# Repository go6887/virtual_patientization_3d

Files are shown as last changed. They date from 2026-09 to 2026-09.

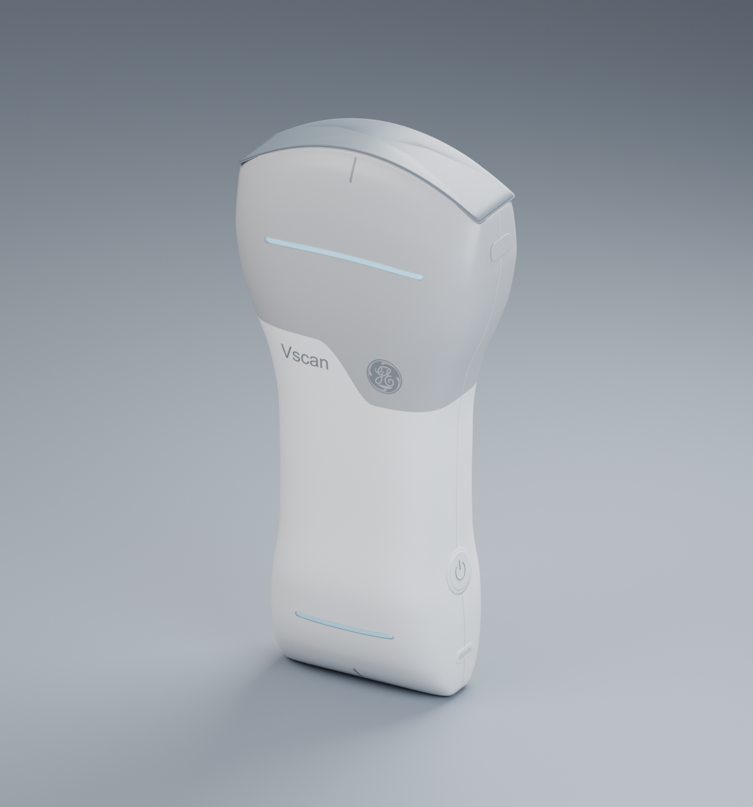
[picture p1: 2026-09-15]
assets/Vscan_Air_CL/Vscan_Air_CL_preview.png

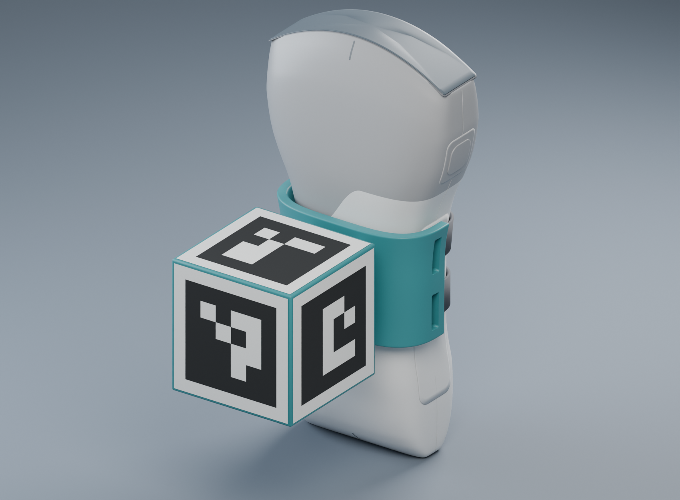
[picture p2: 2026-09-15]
assets/Vscan_marker_attachment/attachment_on_probe.png

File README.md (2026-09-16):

# Vscan Air CL — Webカメラ追跡 / Rerun

プローブに装着した5面のArUcoマーカをWebカメラで検出し、プローブとアタッチメントのOBJをRerun上で動かします。カメラを固定したときの、カメラに対する位置・姿勢を表示します。

`assets/Vscan_marker_attachment/marker_geometry_42mm.json` の **DICT_4X4_50 / ID 0〜4 / 黒枠32 mm / 台42 mm** を使用します。資料のDesktopパスではなく、リポジトリ内のassetsを読み込みます。

## まずデモを動かす

Python 3.14と[uv](https://docs.astral.sh/uv/)を使用します。リポジトリのルートで実行してください。

```bash
uv sync
uv run probe-tracker demo
```

Rerunが開き、左にプローブ・アタッチメント・マーカの3D表示、右に検出画像、下に状態と再投影誤差を表示します。デモは10秒間です。カメラは使わず、移動するマーカ画像を生成して**実際のArUco検出・姿勢推定に通します**。録画のタイムラインを動かして再生できます。

```bash
# デモを記録し、あとから開く
uv run probe-tracker demo --no-viewer --save output/demo.rrd --no-realtime
uv run rerun output/demo.rrd
```

## 腎臓にビームを当てる

`--kidney` を付けると、右腎モデルを小さな立方体（ボクセル）で表示し、プローブの動きに合わせて走査断面との交差を判定します。通常起動では「腎臓の位置・大きさ」操作パネルも開きます。

```bash
# カメラなしで、現在の交差・履歴・非交差を確認
uv run probe-tracker demo --kidney

# 時間制限なしで、操作パネルから移動・拡大縮小を試す
uv run probe-tracker demo --kidney --max-frames 0

# 実物のプローブで操作（プレビュー画面のRキーで履歴を消去）
uv run probe-tracker track --camera 0 --kidney --preview

# 腎臓と走査断面の状態も録画し、あとから再生
uv run probe-tracker demo --kidney --no-viewer --save output/kidney_demo.rrd --no-realtime
uv run rerun output/kidney_demo.rrd
```

- **緑**は現在交差している立方体、**黄**は過去に交差した立方体です。現在の交差を優先して緑で表示します。
- 未走査の外形は、はっきりしたオレンジ色の枠線で表示します。内部まで判定し、立方体間の描画上の隙間は判定に影響しません。
- 状態欄に交差の有無・個数と、累積着色数・割合を表示します。割合の分母は腎臓全体のボクセル数で、現在の交差も履歴に含まれます。
- プレビュー画面を選択して **R** を押すと、現在の交差を残して累積履歴を消去します。次の有効フレームから履歴を再蓄積します。履歴は実行ごとに初期化されます。
- **LOST** の間はプローブ・走査断面・緑の現在色を消し、判定不可（`UNAVAILABLE`）と表示します。固定した腎臓と黄色の履歴は保持し、再検出すると判定を再開します。

操作パネルでは次の操作ができます。画像処理中も操作を受け付け、連続クリックの移動量を合計した最新位置・大きさを次の描画に反映します。

- **位置**：X・Y・Zの数値を入力して適用するか、各軸の＋／−ボタンで移動します。移動量は1・5・10・25 mmから選べます。
- **大きさ**：スライダー、数値入力、＋／−ボタンで**10〜500％**に変更します。100％が元の実寸で、腎臓中心を保って全方向を同じ倍率で拡大・縮小します。
- **初期配置へ戻す**：起動時の位置と倍率に戻します。着色履歴は保持します。
- **履歴を消去**：現在の交差を残して黄色の履歴を消します。
- **終了**：終了ボタンまたは操作パネルを閉じることで追跡を終了します。Ctrl+CやプレビューのQ/Escでも終了できます。

移動や拡大・縮小は表示と交差判定の両方に反映され、LOST中でも配置を変更できます。履歴は腎臓の各ボクセルに付いて動きます。拡縮時はボクセルの一辺も同じ倍率で変わり、ボクセルの個数は変わりません。位置・倍率の変更も録画され、`.rrd`のタイムラインを戻すと当時の配置で表示されます。

操作していない間、腎臓は**カメラ座標に固定**されます。カメラを固定したままプローブを動かしてください。起動時に次のオプションを指定できます。

| オプション | 初期値 | 意味 |
|---|---|---|
| `--kidney-position-mm X Y Z` | `0 -180 400` | 腎臓の境界ボックス中心。カメラ基準でX右・Y下・Z前方、単位mm |
| `--kidney-rotation-deg RX RY RZ` | `0 0 0` | 腎臓中心まわりの回転。固定軸X→Y→Zの順、単位度 |
| `--kidney-scale` | `1` | 腎臓の初期倍率（0.1〜5）。例：`1.5`で150％ |
| `--no-kidney-controls` | 未指定 | 操作パネルを開かずに実行 |
| `--voxel-mm` | `3` | 立方体の一辺（1〜10 mm） |
| `--beam-depth-cm` | `15` | レンズ曲面からの走査深さ（0より大きく24 cm以下） |
| `--beam-angle-deg` | `60` | 走査断面の表示角（0より大きく60度以下） |

```bash
uv run probe-tracker track --kidney --preview \
  --kidney-position-mm 0 -180 400 --kidney-rotation-deg 0 0 30 \
  --beam-depth-cm 15 --beam-angle-deg 60 --voxel-mm 3
```

初期配置は既存の10秒デモで交差と非交差を確認できる位置です。実物では取り付け方向や作業範囲に合わせて位置・角度を指定します。プローブ表示と判定には同じ平滑化済み姿勢を使います。

`--no-viewer`で録画する場合は操作パネルも開きません。明示的に`--kidney-controls`を付ければパネルだけ開けます。パネルはPythonのTkinterを使います。Tkinterが使えない環境では`--no-kidney-controls`を指定し、起動オプションで配置を設定してください。既に保存した録画の再生画面からは操作できないため、配置を変更するときは`track`または`demo`を起動します。

走査断面はプローブOBJのコンベックス側レンズに合わせた、厚みゼロの有限な扇形です。各立方体と面積を持って交差すると着色し、点・辺だけの接触は除外します。実際のビームの厚みや音響強度を再現するものではありません。右腎STLは `assets/kidney/` に同梱し、外部のDesktopフォルダには依存しません。`--kidney` を省略すると従来の追跡表示になります。

## Webカメラで追跡する

```bash
uv run probe-tracker track --camera 0
```

少なくとも1面のマーカ全体をカメラに見せます。複数面が見えると安定しやすくなります。Rerun画面を閉じても取得プロセスは継続するので、終了は実行元で **Ctrl+C**。`--preview` を付けるとOpenCVの小窓でも確認でき、そこで **Q / Esc** で終了できます。

- macOSでカメラを開けない場合は、システム設定 → プライバシーとセキュリティ → カメラで、実行元のターミナルまたはCodexのアクセスを確認します。外付けカメラは `--camera 1` などを試します。
- 初回は水平画角60°を仮定します。概略の動作確認用で、位置・距離の正確さは保証しません。`--fov 70` のように変更できます。
- 校正ファイル `config/camera.json` がある場合は自動で使用します。
- マーカを見失ったとき、または整合する姿勢が得られないときは **LOST** と表示し、現在の3Dプローブを非表示にします。再検出すると復帰します。
- `--smooth 0.35` が標準の平滑化係数です。`--smooth 1` で平滑化を無効にできます。画像上の軸と誤差は平滑化前、3Dモデルと位置表示は平滑化後です。

```bash
# 表示しながら録画
uv run probe-tracker track --camera 0 --save output/session.rrd

# 別の校正ファイル・取得解像度を指定
uv run probe-tracker track --camera 1 --width 1280 --height 720 --calibration config/external_camera.json

# カメラの録画ファイルや静止画を処理
uv run probe-tracker track --video path/to/video.mp4 --calibration config/camera.json
uv run probe-tracker track --image assets/Vscan_marker_attachment/attachment_on_probe.png
```

静止画の組立レンダーは検出確認用です。そのレンダーのカメラ内部パラメータは付属しないため、姿勢・距離の正解値比較には使えません。未校正設定ではIDを検出できても姿勢の品質チェックでLOSTになります。姿勢までの動作確認には `demo` を使用してください。

### LOSTが多い場合の診断

映像上部とRerunの状態欄に、直近60フレームの結果を表示します。ターミナルには2秒ごとの累計と終了時の集計も表示します。LOSTの瞬間を目で追う必要はありません。

```bash
uv run probe-tracker track --camera 0 --width 1280 --height 720 --preview --diagnostics output/tracking_diagnostics.jsonl
```

普段の動かし方で20〜30秒試し、Qで終了します。診断ファイルには各フレームの判定理由、ID、マーカの画素寸法、歪み補正後の四隅、再投影誤差を保存します。再実行時はセッションを追記します。

| 表示・ログの理由 | 意味・切り分け |
|---|---|
| NO ID / `no_markers` | 使用可能なIDがない。距離・ぼけ・反射・遮蔽などを確認。生のIDも記録するので未知ID・重複IDの除外と区別できる |
| POSE / `pose_rejected` | IDは得られたが、再投影誤差・奥行き・面の向きのいずれかが条件を満たさない。これだけで原因を校正誤差に断定はできない |
| CONFLICT / `inconsistent_faces` | 複数面が検出されたが、整合する姿勢に2面以上が同意せず、過去の姿勢でも選べない。貼付位置・IDの面配置・紙の上方向・校正値を確認 |
| CORNERS / `invalid_corners` | 使用可能な四隅になっていない（退化した形、極小領域など） |

現在の実装は1フレームの不採用でLOSTにし、履歴をリセットします。複数面の不整合が続くと、そのままでは復帰しにくい場合があります。一度1面だけを正面寄りに見せて復帰するかが切り分けになります。診断追加によって採用条件や4 pxの閾値は変えていません。

## カメラを校正する

1. チェスボードを生成し、拡大縮小なしの **100%** で印刷します。マーカラベルのPDFとは別の用紙です。

   ```bash
   uv run probe-tracker board --output output/chessboard.svg
   ```

   標準は内側の交点9×6、1マス20 mm、余白込み240×180 mmです。A4横向きで印刷でき、白黒の境界間が20 mmであることを実測します。平らで硬い板に固定してください。

2. 追跡と同じカメラ・解像度で校正を起動します。

   ```bash
   uv run probe-tracker calibrate --camera 0 --width 1280 --height 720
   ```

3. ボード全体が検出されたら **Space** で採用。画面の中央・端、距離、傾きを変え、15枚以上集めます。同じ構図の連続採用は抑制されます。
4. **C** で計算し `config/camera.json` に保存します。**Q / Esc** は保存せず終了します。再投影誤差も出力されます。
5. `uv run probe-tracker track --camera 0` で追跡します。

カメラの画角・クロップ・フォーカス設定を変更した場合は再校正してください。同じアスペクト比の単純な画像リサイズには内部パラメータを拡縮しますが、異なるアスペクト比はエラーにします。同じ比率でもクロップが変わるカメラモードには別の校正が必要です。レンズ歪みを補正した映像を検出・Rerun表示の双方に使用します。

## 座標と表示の意味

全体の単位は **mm**。カメラ座標はOpenCVの **X右・Y下・Z前方** です。推定するのはマーカキューブ中心の `camera_from_cube` です。

資料の組立変換は `probe_from_cube` なので、OBJを表示するときは逆行列を合成します。

```text
camera_from_probe = camera_from_cube @ inverse(probe_from_cube)
```

プローブOBJを原点中心に移動し直したり、メートルとして読んだりしません。プリント用アタッチメントOBJは別の造形座標なので、組立データと照合した変換を適用します。詳細は [assetsの検証記録](docs/asset_validation.md) を参照してください。

1面のときは平面PnPの候補解、複数面のときは各面の候補と非平面の組合せを評価します。再投影誤差、カメラ前方、面の向き、面同士の整合性を確認してから採用します。重複IDや未知のIDは使用しません。単面の正面付近には姿勢の曖昧さが残り、手・反射・ブレで黒枠が欠けると追跡できません。

**カメラ校正とプローブの取り付け校正は別です。** 付属JSONのプローブ位置はCAD上の推定値です。紙・接着層の厚さ、固定位置、再装着のずれは含まれません。表示位置はプローブモデルの原点であり、超音波画像面やレンズの接触点の校正値ではありません。今回の実装は追跡・表示の試作です。

## 構成と検証

```text
src/probe_tracking/
  geometry.py     添付JSONと座標変換
  tracking.py     ArUco検出・姿勢推定・平滑化
  camera.py       内部パラメータの読込と解像度整合
  calibration.py  チェスボードとカメラ校正
  synthetic.py    合成マーカ画像の生成
  viewer.py       Rerunへの形状・姿勢・映像・状態の出力
  kidney_scan.py  固定した腎臓の配置・現在の交差・累積履歴
  kidney_view.py  腎臓ボクセルと走査断面の時系列表示
  kidney_controls.py  腎臓の移動・拡大縮小・履歴消去の操作パネル
  kidney_voxels.py / ultrasound_geometry.py / probe_scan_profile.py
                  腎臓のボクセル化・有限断面との交差・レンズ形状
  cli.py          実機・動画・デモの起動
```

```bash
uv run pytest
uv run ruff check src test
```

テストは5面の姿勢復元、複数面の外れ値、重複・未知ID、検出ロスト、座標変換、校正値の復元を含みます。合成デモとRerun記録を確認しています。実物を用いた追跡精度・カメラ校正の検証は別途必要です。

各オプションは `uv run probe-tracker --help`、`uv run probe-tracker track --help` で確認できます。`uv run python src/main.py demo` も使用できます。

実装時の参照: [OpenCVのPnP](https://docs.opencv.org/4.x/d5/d1f/calib3d_solvePnP.html)、[カメラ校正](https://docs.opencv.org/4.13.0/dc/dbb/tutorial_py_calibration.html)、[Rerun Transform3D](https://rerun.io/docs/reference/types/archetypes/transform3d)、[Pinhole](https://rerun.io/docs/reference/types/archetypes/pinhole)。

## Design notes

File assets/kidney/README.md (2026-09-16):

# Right kidney model

`kidney_right.stl` is copied without modification from the reference application
`/Users/goudamasaki/Desktop/test/kidney_right.stl` supplied for this project.
Its original coordinates and millimetre units are preserved. Runtime code loads
this repository copy and has no dependency on the reference application's path.

The scan places the source mesh's bounding-box centre at the configured camera
position, then applies rotations about that centre. The closed surface is filled
with source-aligned cubes at the requested resolution before applying this pose.

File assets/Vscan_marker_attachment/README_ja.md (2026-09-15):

# Vscan Air CL用・位置追跡マーカーアタッチメント

大きい曲面のプローブ側を使う前提で、背面のくびれに取り付ける試作品です。
曲面に沿うサドル、短い補強支柱、5面マーカー台を一体化しています。
前回作成した写真由来の外観モデルに合わせた設計で、実機への装着は未確認です。

## 最初に使うファイル

| ファイル | 用途 |
|---|---|
| `Vscan_saddle_fit_test.obj` / `.stl` | 先に印刷する、装着確認用のサドルだけの試験片 |
| `Vscan_marker_attachment.obj` / `.stl` | マーカー台を含む一体型の本体 |
| `Vscan_marker_attachment_assembly.blend` | プローブ・ベルト・パッド・貼付位置を確認する組立モデル |
| `marker_labels_32mm.pdf` | この台に合うマーカー貼付紙。A4・100%で印刷 |
| `marker_geometry_42mm.json` | マーカーの寸法、面、向き、四隅の3D座標 |

OBJ/STLは1単位=1 mm。印刷部品だけの、閉じた単一メッシュです。MTLは不要です。
Blenderの組立モデルには印刷しない参考プローブ、ベルト、パッド、紙も含みます。

## 準備するもの

- 3Dプリントした本体1個。まずサドル試験片で装着確認。
- 幅10 mm、長さ約200 mmの、伸びにくい面ファスナーバンド2本。
  両端を穴で折り返して固定できる薄いタイプを使用します。必要な長さは実物で調整。
- 10 × 12 mm、厚さ1 mmのシリコンパッド4枚と薄い接着層。
  緩い箇所には0.5 mm刻みで薄いシムを追加します。
- マーカーを貼るための薄い接着材。紙を平らに保ちます。

## 取り付け

1. 大きい曲面レンズを上に、Vscanの文字がある面を正面にして、組立画像と同じ向きに置きます。
2. サドルの内側にパッドを4枚貼ります。左右2か所×上下2か所で、帯を通す穴から離します。
   初期厚さは1 mm。厚いスポンジではなく薄いパッドで隙間を調整します。
3. プローブの背面側にサドルを当てます。上縁は中央の白いくびれ、下縁は電源ボタンより上です。
   内面は参考モデルより約1.6 mm離してあります。実物の形に合わせ、パッドを局所的に調整します。
4. 上下それぞれのバンドを、左右の穴を端部アンカーとしてプローブ前面側に回します。
   バンド両端を各穴に1枚の厚みで通し、サドル前縁の肉部分に回して、前面側のバンド自身へ折り返して留めます。
   折り返した二重部分は穴の外に置きます。穴は約11.4 × 3.2 mmです。
   支柱のあるサドル背面を横切る戻り経路は使いません。
5. レンズ、電源ボタン、表示ランプを避けたまま固定します。
   キューブを軽く押し、プローブとの相対的なずれや揺れを確認します。実機の握り方も確認してください。
6. サドル試験片の装着が良ければ、本体を印刷して同じパッド構成・位置で取り付けます。

パッドや締め付けでは収まらない形状差がある場合は、実測して内面を修正してください。
力ではめ込むスナップ式にはしていません。充電・清掃時には外せる構成です。

## 印刷の開始条件

機種・材料に合わせて調整するための初期案です。

- 材料：PETGを想定。試験片はPLAでも形状確認が可能。
- ノズル0.4 mm、積層0.2 mm、外周4本、上下6層、インフィル15〜20%を目安に設定。
- サポートを有効にします。サドル下面には造形物上から始まるサポートも必要です。
- OBJ/STLは、キューブのID0面をベッド側に向けてあります。本体外寸は約54.3 × 42 × 70 mm。
- 角やベルト穴、パッドが当たる面のサポート痕を仕上げます。マーカーを貼る平面を曲げないでください。

キューブは外形を閉じたCAD形状です。スライサーのインフィル設定で内部を軽くします。
100%充填を前提とした設計ではありません。実際の重量・造形時間はスライサーで確認してください。

## マーカーの貼り方と追跡設定

台の外寸は42 mm角、黒枠は32 mm角、貼付紙は40 mm角です。
同梱PDFをA4・100%で印刷し、100 mm確認スケールと黒枠32 mmを実測してください。
元の50 mmキューブ／黒枠40 mm用の設定は、そのままでは一致しません。

| ID | 組立時の面 | 紙の上方向 |
|---|---|---|
| 0 | プローブから最も離れた背面側 | 大きい曲面レンズ側 |
| 1 | プローブ正面から見て左側 | プローブから離れる方向 |
| 2 | 大きい曲面レンズ側 | プローブから離れる方向 |
| 3 | プローブ正面から見て右側 | プローブから離れる方向 |
| 4 | 小さい平面レンズ側 | プローブから離れる方向 |

各紙を面の中央、各辺から1 mm内側に貼ります。支柱が付く面には貼りません。
組立モデルの黒白模様は貼付位置を示す参考表示で、印刷用OBJ/STLには入っていません。

`marker_geometry_42mm.json`は説明用の幾何データです。既存の`marker_model.json`と同じ形式とは限りません。
使用する追跡ソフトに、黒枠寸法・各面の位置・向き・角の順序を反映してください。
JSON内のプローブとの位置関係はCAD上の推定値で、実機での校正結果ではありません。
紙・接着層の厚み、実際の固定位置、プローブ基準点や超音波画像面との対応は実機で校正してください。
再装着やパッド構成変更時も、この対応を確認します。

## 今回確認した範囲

- 本体・試験片とも、単一の閉じたメッシュ。OBJ/STLの面・接続・再読み込みを検証済み。
- 参考プローブの全部品との幾何学的な交差なし。
- 5面のマーカー四隅は所定の平面上。PDFのIDは元資料と一致。
- 組立レンダーから、見えているID0・1・2およびID3をOpenCVで検出。

実物のはまり方、保持力、印刷強度、カメラ実写での追跡精度は未検証です。
まず机上で試験片の装着と固定を確認するための初回試作として使用してください。

作成：2026-09-10 / Blender 5.2.1

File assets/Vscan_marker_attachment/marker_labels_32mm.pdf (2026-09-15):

# プローブアタッチメント / マーカー貼付紙

42 mm キューブ用・ArUco DICT_4X4_50・ID 0〜4

このPDFを A4・倍率100%（実際のサイズ）で印刷してください。

「用紙に合わせる」は無効。元PDF用の80%設定は、このPDFには使いません。

黒枠の外寸：32 × 32 mm / 切り取り枠：40 × 40 mm / 白い余白：各4 mm

切る前に、IDと紙の上方向を裏面に記入。42 mmの各平面の中央に貼ります。

ID 0 / +Z 面（天面）

紙の上側を +Y 方向へ

ID 1 / +X 面

紙の上側を +Z 方向へ

ID 2 / +Y 面

紙の上側を +Z 方向へ

ID 3 / -X 面

紙の上側を +Z 方向へ

ID 4 / -Y 面

紙の上側を +Z 方向へ

### 貼り付けの基準

紙の白い枠も残して切る。

台の各辺から1 mm内側に

40 mm角の紙を配置する。

-Z 面は取付部。貼付なし。

原点：キューブ中心。面・ID・紙の向きは添付の座標JSONと一致させてください。

座標JSONは幾何情報の見本です。使用する追跡ソフトの形式に合わせて設定します。

紙・接着層の厚みと取付後の姿勢を反映し、プローブ／超音波画像面との対応を校正。

印刷後に実測：下のスケール100 mm、各マーカー黒枠32 mm、切り取り枠40 mm。

0 | 100 mm

研究・机上試作用 / 実物への装着・追跡精度は未検証 / 1ページ

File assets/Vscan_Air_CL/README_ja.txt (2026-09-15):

GE HealthCare Vscan Air CL — 外観3Dモデル

同梱ファイル
・Vscan_Air_CL.obj：形状データ（部品別メッシュ、UV、法線付き）
・Vscan_Air_CL.mtl：色と材質の定義
・Vscan_Air_CL.blend：編集用のBlender 5.2ファイル
・Vscan_Air_CL_preview.png：モデルのプレビュー

使い方
OBJとMTLを同じフォルダに置いて読み込んでください。
外部テクスチャは使用していません。ロゴと文字もメッシュです。
Blenderで編集する場合は、同梱の.blendを開くと材質・表示設定も引き継げます。

寸法・座標
OBJの1座標単位 = 1 mm。
外形寸法：全長131 mm × 最大幅64 mm × 最大厚み31 mm。
X：幅、Y：厚み、Z：長さ。正面は -Y、コンベックス側は +Z。
原点は全体の外接範囲の中心です。
OBJ自体に単位情報はないため、読み込み先をmmとして扱ってください。
Blenderファイルはメートル法、単位スケール0.001、長さ表示mmに設定しています。

作成内容と精度
製品写真と公表外寸を基に、Blenderで作成した外観の近似モデルです。
本体のくびれ、灰色と白の境界、両端のレンズ、表示ランプ、側面ボタン、
カバー、継ぎ目、方向マーク、Vscan文字とGEロゴを再現しています。
局所の曲率、厚さ、細部の寸法は写真からの推定です。
メーカー公式CAD、内部構造、寸法保証付きの設計データではありません。
各部品が重なる外観用の構成です。単一の造形用ソリッドにはしていません。

主な参照資料
GE HealthCare 日本 製品ページ
https://www.gehealthcare.com/ja-jp/products/ultrasound/vscan-air-cl

GE HealthCare 公式寸法・仕様
https://vscanair-support.gehealthcare.com/support/solutions/articles/47001172608-specifications

GE HealthCare プローブ各部の説明
https://vscanair-support.gehealthcare.com/support/solutions/articles/47001169691-probe-description

GE製ユーザーマニュアル、図3-3（販売店サイトに掲載）
https://apps.soundvet.com/vscan/assets/files/Vscan_2022_user_manual-a0678ce56d8e4ea7b74bcee32e6f62a7.pdf

製品各方向の写真参考
https://quincemedical.com/products/ge-healthcare-vscan-air-portable-ultrasound-systems

GEモノグラムの形状資料
https://upload.wikimedia.org/wikipedia/commons/f/ff/General_Electric_logo.svg

制作：2026-09-06 / Blender 5.2.1

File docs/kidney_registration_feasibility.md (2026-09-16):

# 腎臓セグメンテーションを用いた3Dモデル位置合わせの調査

調査日: 2026-09-16。対象は両リポジトリの現在の作業ツリー。コード・既定checkpointのメタデータ・同梱メッシュ・一次資料を確認した。実機撮像、患者画像や動画の読み込み、セグメンテーション推論、登録精度の実測は行っていない。

提案の「腎臓セグメンテーション→長軸推定→3Dモデルの位置・向き・大きさ合わせ」は、初期配置として有望。推奨する構成は、**良好な長軸断面から仮配置し、追跡済みの複数断面で配置を補正・確定する方法**である。モデルを新規学習する前に、画像とマーカーの空間校正・時刻同期を整える必要がある。現在の情報だけでは、実物の腎臓に対するmm単位の精度や、3 mmボクセルの正確な着色までは保証できない。

現在の実装で確認できた内容は次のとおり。

| 対象 | 確認した事実 | 位置合わせへの意味 |
|---|---|---|
| プローブ追跡 | `camera_from_cube` を推定し、CADの `cube_from_probe` と合成 | 6DoFの位置・姿勢を利用できる。ただしCADと実際の画像面の関係は別途校正が必要 |
| 腎臓配置 | カメラ座標に固定。既定中心は `(0, -180, 400)` mm | 実際の腎位置を観測して置いたものではない |
| 腎臓変換 | 起動時に回転を指定可能。実行中の `set_placement` は位置と等方スケールのみ | 登録結果を反映するには回転も更新できる入口が必要 |
| 走査断面 | プローブOBJ外形のレンズから推定した有限の扇形 | 実際の超音波画素との対応が未校正。表示と登録で同じ校正済み幾何を使う必要がある |
| 交差判定 | 厚みゼロの扇形とボクセルの交差を判定 | 幾何学的な通過履歴。超音波で実際に見えた範囲や画像品質の保証とは区別する |
| 腎臓メッシュ | 右腎の閉じたSTL。現在の被験者・ファントムとの形状一致を示す情報はない | 汎用テンプレートとして使う。等方拡縮で個体形状まで一致するとは限らない |

実装の根拠: [姿勢の合成と交差更新](/Users/goudamasaki/ghq/github.com/go6887/virtual_patientization_3d/src/probe_tracking/cli.py:324)、[腎臓の初期配置](/Users/goudamasaki/ghq/github.com/go6887/virtual_patientization_3d/src/probe_tracking/kidney_scan.py:97)、[実行中の位置・スケール更新](/Users/goudamasaki/ghq/github.com/go6887/virtual_patientization_3d/src/probe_tracking/kidney_scan.py:139)、[外形からの走査面推定](/Users/goudamasaki/ghq/github.com/go6887/virtual_patientization_3d/src/probe_tracking/probe_scan_profile.py:1)、[CADと実機校正の区別](/Users/goudamasaki/ghq/github.com/go6887/virtual_patientization_3d/docs/asset_validation.md:15)。

同梱STLを読み取った結果、座標軸に沿った外接寸法は約52.59 × 53.26 × 98.44 mm、体積は約120.56 cm³。これらはメッシュの測定値であり、実物の腎寸法ではない。現在の配置基準は外接箱中心で、メッシュの体積重心とは約1.81 mm異なる。登録で求めた「中心」が画像重心、体積重心、外接箱中心のどれかを明確にし、変換するときに混同しない。

参考リポジトリの既定モデルは、`models/segmentation/best.pt`。checkpointを安全な重み読み込みで確認したところ、**SegFormer / MiT-B4、512 × 512グレースケール入力、単一フレームの2Dモデル**だった。クラスは背景・`renal_cortex`・`central_echo_complex`。ラッパー名は `Mid25dSegmenter` だが、既定checkpointの `n_frames` は1である。2.5D候補も存在するが、その時間窓は3D位置や断面間隔を復元するものではない。

入力はクロップ済み画像で、推論用にリサイズした後、出力マスクをクロップ後の元解像度へ戻す。そのため、3D変換に使うのは表示用の縮小画像や512²入力上の座標ではなく、クロップ・リサイズを追跡した画像座標である。[モデル設定](/Users/goudamasaki/ghq/github.com/go6887/virtual_patientization/src/configs/constants.py:51)、[checkpointからのモデル構築](/Users/goudamasaki/ghq/github.com/go6887/virtual_patientization/src/segmentation/factory.py:13)、[推論と座標復元](/Users/goudamasaki/ghq/github.com/go6887/virtual_patientization/src/segmentation/mid25d.py:145)。

既存コードは皮質とCECの和集合を結合腎領域として利用し、全画素の重心・共分散からPCA長軸を求めている。この計算を初期配置の参考にできる。ただし、既存関数の出力は病変配置用アンカーであり、3D姿勢推定APIではない。外輪郭を腎全体の輪郭の近似として使えるかは、対象データのアノテーション定義と手動の腎外輪郭で確認する。[PCA実装](/Users/goudamasaki/ghq/github.com/go6887/virtual_patientization/src/lesion/placement.py:242)。

このPCAの符号は画面右下方向にそろえており、解剖学的な上極・下極の判別ではない。また、ほぼ円形のマスクでは画面x/y軸にフォールバックする。3D登録へ移す際は、こうした断面を「長軸の信頼性が低い」と扱う必要がある。長軸の計算は物理スケールを反映した座標で行い、縦横倍率の異なるリサイズ画像から得た角度をそのまま使わない。

既定checkpointに保存されたvalidation Diceは皮質0.79432、CEC0.78542、平均0.78987だった（validation `job10`、epoch21）。今回再評価した値ではなく、腎全体の外輪郭精度・長軸角度・3D位置誤差を表す値でもない。別の2.5D候補の約0.896という値は別モデル・別分割であり、同一元動画の重複などの留保がある。未知の人、装置、ファントムに対する性能は別に評価する必要がある。[2.5D候補の評価条件と限界](/Users/goudamasaki/ghq/github.com/go6887/virtual_patientization/docs/cvat_primary_25d_area_threshold_calibration.md:62)。

単一断面から直接観測できるのは、腎臓全体ではなく「撮影平面と腎臓が交差した断面」である。以下は幾何学的な判断であり、今回の実機実験結果ではない。

| 2Dマスクから得る量 | 初期値への利用 | 確定できないこと |
|---|---|---|
| マスク重心 | 断面の中心を3D位置へ変換 | 腎臓全体の中心が断面外にどれだけ離れているか |
| PCA長軸 | 断面内の主方向を3D方向へ変換 | 本当に3D長軸を含む断面か、長軸回りの回転、上極・下極 |
| 長径 | 良好な中心長軸断面ならスケールの初期値 | 見かけの短さが個体サイズによるのか、切り方によるのか |
| 短径 | 断面内の幅の初期値 | 断面外の厚みと個体固有の形状 |

仮想的な楕円体で考えると、長さ110 mm、奥行50 mmの物体を、中心から奥行方向に15 mmずらした長軸に平行な平面で切ると、断面の長さは88 mmになる。断面の縮小率は `sqrt(1 - (15/25)^2) = 0.8`。これは「物体全体を0.8倍にし、中心を撮影平面まで移したモデル」の中心断面と同じである。したがって完全なセグメンテーションでも、単一断面のサイズと面外位置を区別できない例がある。数値は原理の説明用であり、実腎臓の測定値ではない。

形状が正確に既知で非対称なモデルなら、単一断面の輪郭全体への当てはめで姿勢推定が成立する場合もある。しかし、汎用腎モデル・個体差・見切れのある画像で、一意かつ安定した配置を期待する根拠には乏しい。「細長い断面が得られた」というだけで真の長軸断面を確認したことにはならない。

画像を3Dへ置くために必要な変換は、次のように整理できる。

```text
超音波画素 (u, v)
  → g(u, v): 画像平面内の物理座標 [mm]
  → marker_from_image: 画像平面からプローブマーカーへの校正変換
  → camera_from_marker(t): その画像を撮影した時刻の追跡姿勢
  → カメラ座標中の3D点

p_camera = camera_from_marker(t) @ marker_from_image @ g(u, v)
```

`g` は同次座標として表し、画像形式に応じて定義する。通常の表示済みBモード画像なら画像上の物理スケール・原点・左右反転・クロップを扱う。生のビーム角度/距離データなら対応する扇形変換が必要。扇形に見える表示画像を、その理由だけで再び極座標変換しない。深度、ズーム、クロップ、解像度を変えた場合は、校正との対応を確認する。

**画像面からマーカーへの変換を直接校正すれば、写真由来OBJの音響形状を正しいと仮定する必要はない。** その校正値から3D表示の走査面と着色判定も定義する。腎臓だけを移動して見た目を合わせると、プローブを別方向へ動かした際に画像面の誤差が再び現れる。

空間校正には、既知位置の点・ワイヤーなどを異なるプローブ姿勢から撮像する方法がある。カメラ内部パラメータの校正とも別の工程である。現状は内部校正JSONが指定されなければ仮の画角から内部パラメータを作るため、実物への登録では校正済みカメラと実寸のマーカーを使う。[カメラ設定](/Users/goudamasaki/ghq/github.com/go6887/virtual_patientization_3d/src/probe_tracking/cli.py:254)。画像面と追跡センサーの相対姿勢を求める必要性は、[Pragerらのfreehand US校正論文](https://pubmed.ncbi.nlm.nih.gov/9740387/)でも扱われている。

時刻は「推論が終わった時刻」ではなく「画像内容が取得された時刻」に対応させる。参考リポジトリには受信時刻から映像遅延を引く設計があるが、現在の `CAPTURE_LATENCY_S=0.180` を別構成へそのまま移せない。コメントに残る測定条件と数値にも留保があり、超音波装置内・キャプチャ経路・Webカメラ経路を含む相対遅延を再測定する。[遅延設定](/Users/goudamasaki/ghq/github.com/go6887/virtual_patientization/src/configs/constants.py:39)、[内容時刻への補正](/Users/goudamasaki/ghq/github.com/go6887/virtual_patientization/src/processing/pipeline.py:109)。時刻オフセットを測る公式実装例は [PLUS Toolkit](https://github.com/PlusToolkit/PlusLib/blob/master/docs/algorithms/AlgorithmTemporalCalibration.md) にある。固定オフセットの補正だけでは可変の遅延は消えない。

現在の3d側はWebカメラ取得前の経過時間を記録しており、超音波映像と共通の内容時刻で結ばれてはいない。また、登録に使う姿勢をそのまま表示用の平滑化姿勢にすると移動中の遅れを含む。最初は静止姿勢で撮影し、続いて内容時刻に合わせた姿勢補間を評価する。[時刻と平滑化](/Users/goudamasaki/ghq/github.com/go6887/virtual_patientization_3d/src/probe_tracking/cli.py:374)。

参考リポジトリのマスク後処理にも注意が必要。既定ではEMAを使用し、品質不良時は直前マスクを最大2フレーム保持する。3D点群を作るときに古いマスクを新しいプローブ姿勢で変換すると、架空の輪郭が生じる。初期検証では現在フレームのマスクと連結成分処理を使い、EMA保持を外す方法が分かりやすい。現在のAPIはマスクと処理時間のみで、確率や保持中フラグは返さないため、品質情報が必要なら拡張する。[後処理設定](/Users/goudamasaki/ghq/github.com/go6887/virtual_patientization/src/configs/constants.py:54)、[結果型](/Users/goudamasaki/ghq/github.com/go6887/virtual_patientization/src/segmentation/base.py:23)。

具体的な初期検証は、以下の順番を推奨する。いずれもこれから実施する設計案である。

1. **固定ファントムで画像面校正を検証する。** カメラ・ファントム・マーカー取付を固定し、深度と表示条件をそろえる。校正に使わなかった点やワイヤーを複数姿勢から再構成して、mm単位の誤差を確認する。ファントムのCAD/CTと外部マーカーの関係が既知なら、その配置を独立した正解または比較基準にできる。
2. **良好な長軸像で仮配置する。** 最初は人が、両極が見え、見切れていない断面を選ぶ。現在フレームの腎外輪郭、PCA方向、物理長径を使って位置・長軸・等方スケールの初期値を作る。軸回りの向きと上下極の候補は保留または人が補助する。
3. **複数断面で補正する。** 長軸像に加えて短軸方向や位置を変えたスイープを取得し、腎臓の中央だけでなく両極と幅・厚み方向を観測する。直交2枚は比較案として有用だが、それだけで必ず確定できるとはしない。十分な範囲を覆う平行断面群も利用できる。
4. **位置3・回転3・等方スケール1を最適化する。** 初期実装では輪郭点だけを3D化してモデル表面へ合わせる。マスク内部画素は表面点として使わない。部分点群のPCAは偏るので、主軸の推定だけで配置を確定しない。上下極の向きや長軸回りの回転は複数の初期候補から探索し、初期値を変えても結果が安定するか確認する。
5. **断面一致で確定・評価する。** モデルを各撮影平面で切った輪郭と観測マスクを比較する。輪郭距離と領域一致を利用し、視野外や画像端による見切れは本来の腎表面と区別する。部分点群から表面への片方向距離だけでは、画像にないはずの領域へのモデルの広がりを十分に検出できない。
6. **配置を確定してから走査履歴を蓄積する。** 登録の修正中に着色履歴をためると、誤った配置で付いた色も残る。初期登録の確定時に履歴をリセットする。静止した腎臓の初期登録誤差だけを後から修正する場合は、保存した撮影姿勢と画像幾何から交差を再計算できる。呼吸や体動で腎臓自体が動いた場合は、最新配置を全過去の姿勢に適用しない。各時刻の腎配置・基準座標変換を使って腎臓の局所座標に履歴を集約するか、状態の変化ごとに履歴を区切る。

最適化は、例えば各観測マスクと予測断面の `1 - Dice`、mm単位の輪郭距離、極端なスケールを避ける弱い制約を組み合わせられる。異なる単位の損失には重みを設定する。未知変数は最初は7自由度にとどめ、位置誤差を不自然な変形で吸収しないようにする。長さ・幅・厚みを別々に変える方法や非剛体変形は、複数方向の観測を確保した後に検討する。左右腎も同じ形状とは仮定しない。

比較する方法は「単一長軸像」「長軸＋短軸像」「複数断面スイープ」の3通り。まず手動マスクで幾何処理を評価し、次に同じデータの自動マスクへ置き換えると、校正・形状の問題とセグメンテーションの問題を分けて判断できる。校正と登録を同じ未知の腎形状だけで同時に合わせると、双方の誤差が打ち消し合う可能性があるため、最初は校正を独立に確認する。

評価は、独立した正解に対する中心誤差、長軸角度誤差、寸法誤差、表面距離を測る。登録に使っていない別スイープの断面一致も確認する。画像の隣接フレームをランダムに分けるだけでは、ほぼ同じ観測での評価になる。真の3D形状がなければ、未使用断面の整合性と再現性までは評価できても、絶対的な3D正確さを実証したことにはならない。

この用途では、最終的に**着色されるべきブロックの取りこぼしと誤着色**を評価することが重要。既定ボクセルは3 mmなので、数mmのずれでも境界近くで色が変わり得る。スケール変更時にはボクセル寸法も変わる。画素単位のDice、カメラの再投影誤差、文献の別装置での精度だけで着色精度を説明しない。

人体では初期登録に加え、呼吸・体動・プローブ圧迫による移動を扱う必要がある。患者/ファントム側の基準マーカーを置けば、カメラや身体全体の移動を基準座標で補正できるが、皮膚マーカーだけでは内部の腎臓の呼吸運動や変形までは測れない。まず同じ呼吸状態の短い取得区間に対象を限定し、その後に超音波観測による再登録や呼吸への対応を検討する。反復する息止めも毎回同じ位置を保証しない。[腎臓の呼吸運動をcine MRIで評価した研究](https://pubmed.ncbi.nlm.nih.gov/23475278/)。

直接近い先行例として、2026年の [Ma & Zhangのプレプリント](https://arxiv.org/pdf/2602.16641) は、追跡付き2D腎輪郭から部分点群を作り、テンプレートへの制約付きICPで位置・長軸を推定している。提案方向の実現可能性を支持するが、人体評価は2名、右腎、短時間の息止めを仮定する。人体で報告された誤差は熟練者が選んだ長軸撮像プローブ姿勢との差であり、真の腎表面に対する絶対3D位置誤差ではない。汎用モデルの自由なサイズ推定や、本構成の3 mm着色精度を実証した資料としては扱えない。

患者別CTを用いた [Chiらの2D US–3D CT登録研究](https://arxiv.org/pdf/2305.13855) もあるが、患者別の形状情報と専用登録モデルを使う設定であり、現在の汎用STLにセグメンテーションを接続するだけの設定とは条件が異なる。

実装へ進む場合、初段は既存環境でセグメンテーションを実行してマスク・画像条件・内容時刻を保存し、3d側で追跡姿勢と対応させるオフライン検証が適している。両repoはPython下限、Rerun制約、OpenCV配布パッケージなどが異なるので、アプリ全体をそのまま相互importするより、画像認識と登録の境界を明確にした方が検証しやすい。リアルタイム化の際は、推論の処理時間と撮影時刻の対応を保ち、表示用スレッドを止めない構成を別に評価する。

次に実施する価値が最も高いのは、**既存セグメンテーション＋手動長軸選択による仮配置を、固定ファントムの複数追跡断面で補正し、別スイープで検証するPoC**である。新しい3D認識モデルを作る前に、この実験で校正誤差、単一断面の曖昧さ、汎用形状の限界を切り分けられる。

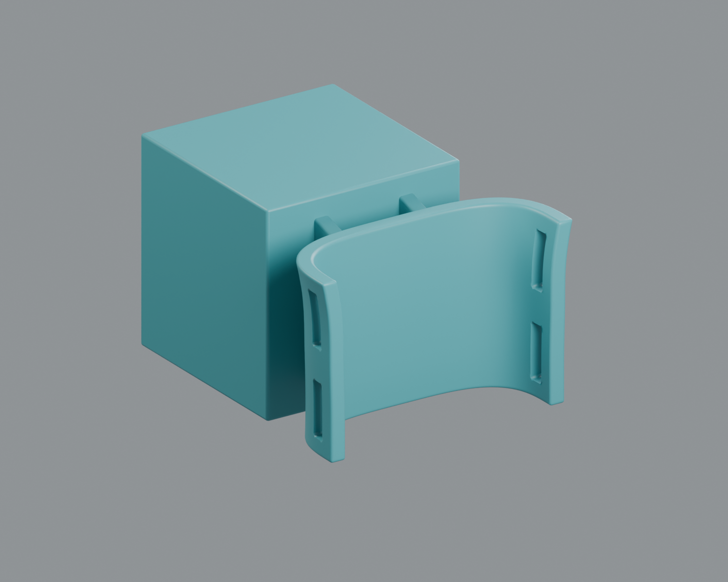
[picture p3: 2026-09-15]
assets/Vscan_marker_attachment/attachment_detail.png

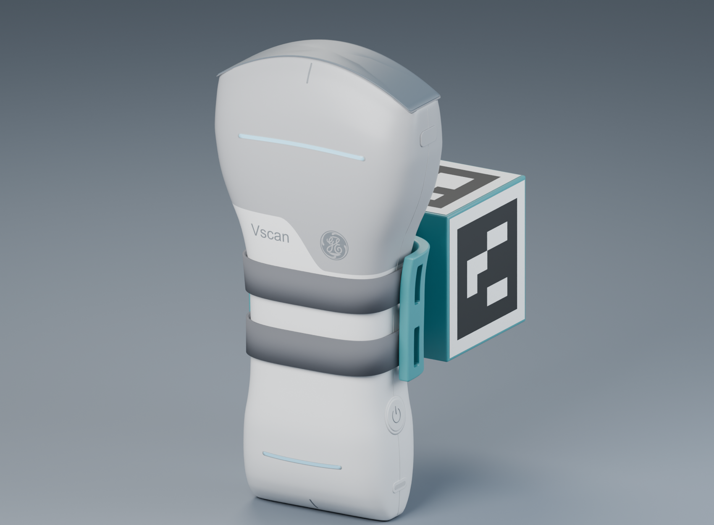
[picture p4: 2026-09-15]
assets/Vscan_marker_attachment/attachment_front_view.png

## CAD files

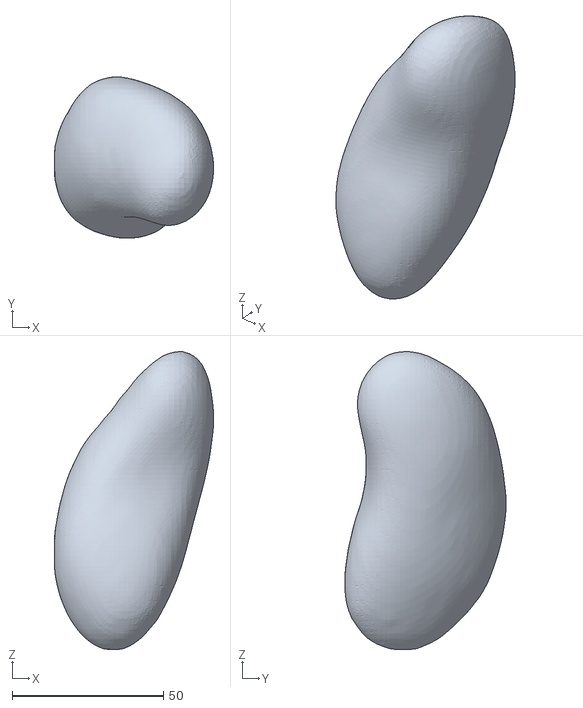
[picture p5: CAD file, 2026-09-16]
assets/kidney/kidney_right.stl
52.6 x 53.3 x 98.4

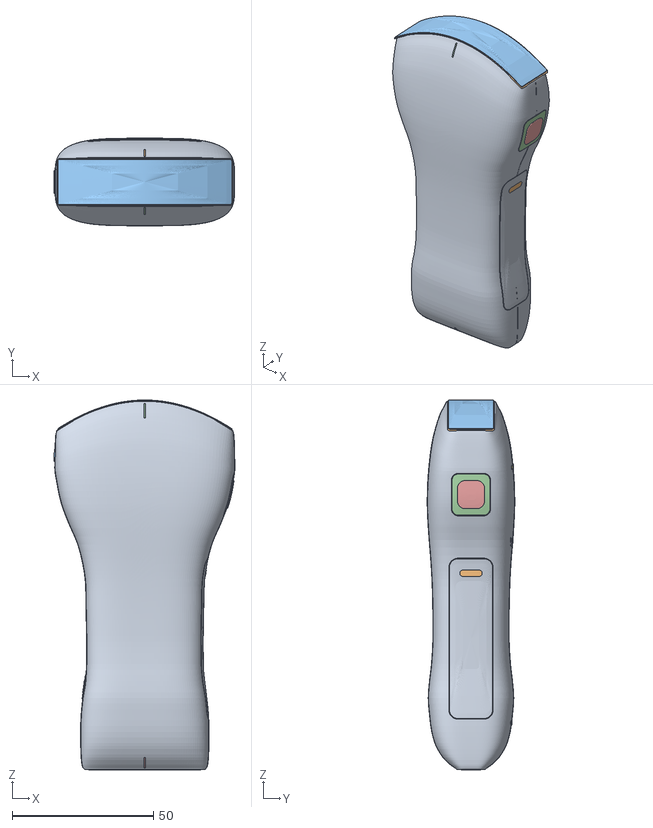
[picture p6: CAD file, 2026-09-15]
assets/Vscan_Air_CL/Vscan_Air_CL.obj
64.0 x 31.0 x 131.0
01_Continuous_ergonomic_shell
02_Convex_lens_perimeter
03_Convex_acoustic_lens
04_Linear_lens_perimeter
05_Linear_acoustic_lens
06_Curved-head_indicator_recess
07_Curved-head_blue_light_guide
08_Linear-head_indicator_recess
09_Linear-head_blue_light_guide
10_Convex_alignment_mark_front
11_Linear_alignment_mark_front
10_Convex_alignment_mark_rear
11_Linear_alignment_mark_rear
12_Housing_parting_line_-1
12_Housing_parting_line_1
13_Battery_cover_perimeter
14_Battery_cover_panel
15_Battery_cover_latch
16_Sealed_service_door_perimeter
17_Sealed_service_door
18_Service_door_grip
19_Power_button_surround
20_Power_button_bezel
21_Power_button
22_Power_symbol_arc
23_Power_symbol_stem
24_Curved-head_tactile_index
24a_Lower_molded_recess_surround
24b_Lower_molded_recess
25_Vscan_wordmark
26_GE_monogram

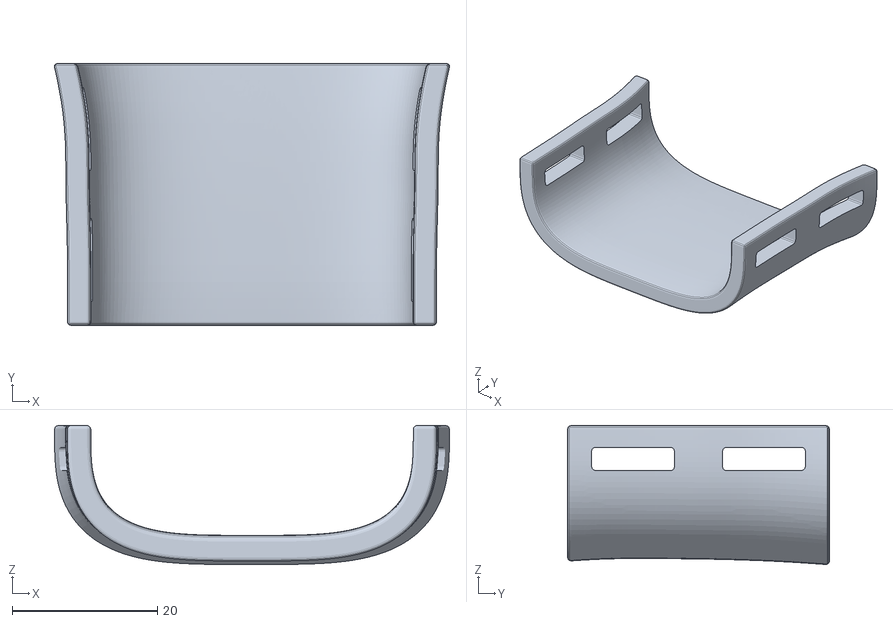
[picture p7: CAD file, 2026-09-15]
assets/Vscan_marker_attachment/Vscan_saddle_fit_test.stl
54.3 x 36.0 x 19.1

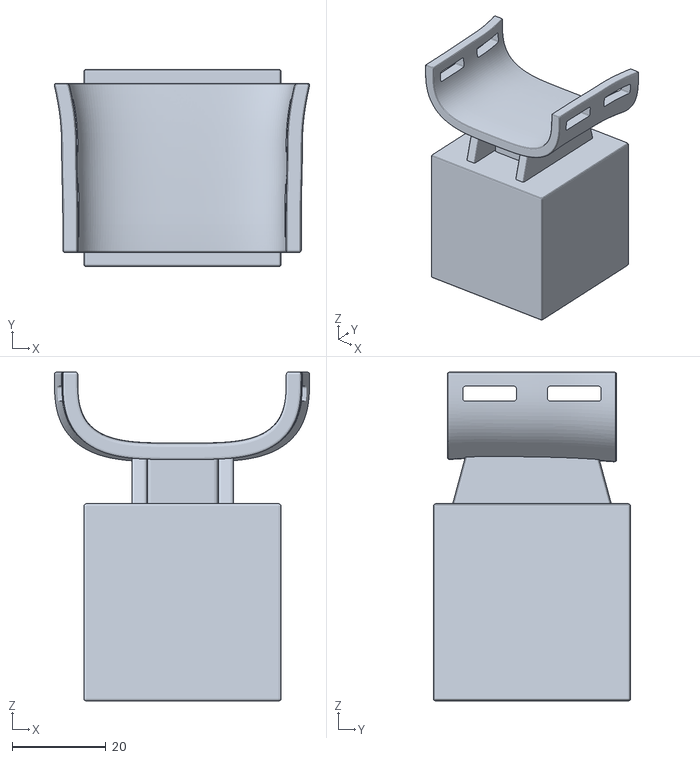
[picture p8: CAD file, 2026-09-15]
assets/Vscan_marker_attachment/Vscan_marker_attachment.stl
54.3 x 42.0 x 70.0

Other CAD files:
assets/Vscan_Air_CL/Vscan_Air_CL.blend
assets/Vscan_marker_attachment/Vscan_marker_attachment.obj
assets/Vscan_marker_attachment/Vscan_marker_attachment_assembly.blend
assets/Vscan_marker_attachment/Vscan_saddle_fit_test.obj

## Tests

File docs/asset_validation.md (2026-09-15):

# 同梱アセットの座標確認

2026-09-11 にリポジトリ内の資料を確認。
ユーザーが指定した Desktop のパスは存在しなかったため、`assets/` の同名資料を参照した。

- `Vscan_marker_attachment/attachment_on_probe.png` と `attachment_front_view.png` を目視確認。
- `marker_labels_32mm.pdf` の全1ページを150 dpiで描画して確認。ArUco `DICT_4X4_50`、ID 0〜4、黒枠外寸32 mm、紙40 mm、キューブ42 mm。面のIDと紙の上方向はJSONと一致。
- `Vscan_Air_CL/README_ja.txt` によるとOBJは1単位=1 mm。プローブのXは幅、Yは厚み、Zは長さ、正面は−Y、コンベックス側は+Z。
- `marker_geometry_42mm.json` の四隅は黒枠の外周。印刷時の白い余白を32 mmに含めない。

OpenCVによる照合でも、JSON内の各6×6白黒パターンは辞書のID 0〜4と完全一致。
PDFの描画画像からID 0〜4、`attachment_on_probe.png` からID 0・1・2、
`attachment_front_view.png` からID 3を検出した。

## プローブOBJとマーカーキューブ

JSONの `nominal_probe_assembly_transform` は、キューブからプローブOBJへの変換。

```text
p_probe = R @ p_cube + [0, 49, -8]  # mm

R = [-1  0  0]
    [ 0  0  1]
    [ 0  1  0]
```

したがってキューブを親にプローブOBJを配置する場合は、この変換の逆を使う。
JSONはCAD上の推定変換と明記している。実機との一致、再装着によるずれ、超音波画像面との対応は未校正。

## 印刷用アタッチメントOBJとマーカーキューブ

印刷用 `Vscan_marker_attachment.obj` はID0をベッド側に向けた別座標系。
次の変換で、JSONのキューブ座標と一致する。

```text
p_cube = diag(-1, +1, -1) @ p_print + [0, 0, 21]  # mm
```

根拠は同梱 `Vscan_marker_attachment_assembly.blend` の
`Vscan marker attachment | printable` メッシュとの頂点照合。
印刷用OBJからBlender組立座標（プローブ座標）への変換は以下。

```text
p_probe.x = p_print.x
p_probe.y = 70 - p_print.z
p_probe.z = p_print.y - 8
```

Blender 5.2.1で両メッシュの13,848頂点を照合し、最近傍頂点距離の最大値は
0.00000430 mm、平均値は0.00000112 mmだった。上記とJSONの逆変換を合成して
印刷用OBJからキューブへの変換を求めた。

この検証が保証するのは同梱CAD同士の整合性であり、実物の取付位置ではない。

## カメラなしデモの検証

`synthetic.py` は実際のArUco画像を3D四隅へ投影し、白い余白、裏面除去、
奥行き順の描画を行う。生成時の正解姿勢を追跡器へ渡さず、画像検出とPnPで姿勢を復元した。
水平画角60度、歪みなし、`demo_pose()` の0〜40秒を0.5秒間隔で検証した結果は以下。

| 解像度 | 姿勢を復元できたフレーム | 使用した面数 | 最大並進誤差 | 最大回転誤差 | 最大再投影RMS |
|---|---:|---:|---:|---:|---:|
| 1280×720 | 81 / 81 | 3 | 約2.72 mm | 約0.77度 | 約0.92 px |
| 640×480 | 81 / 81 | 2〜3 | 約5.52 mm | 約1.67度 | 約1.40 px |

これは画像の画素化を含む合成画像テストの結果。実写の精度評価ではない。

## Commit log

2026-09-11 chore: uvでPythonプロジェクトを初期化
2026-09-11 refactor: main.pyをsrcディレクトリへ移動
2026-09-11 chore: uv.lockを追加
2026-09-15 chore: .gitignoreに生成物・校正ファイル・rrdの除外を追加
2026-09-15 chore: 追跡用の依存関係とビルド・テスト設定を追加
2026-09-15 chore: Vscan Air CLプローブとマーカーアタッチメントの3Dアセットを追加
    [Vscan_Air_CL.blend, Vscan_Air_CL.obj, Vscan_marker_attachment.obj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]
2026-09-15 feat: ArUcoマーカーによるプローブ追跡とRerun表示を実装
2026-09-15 test: プローブ追跡・カメラ校正・表示のテストを追加
2026-09-15 docs: READMEに使い方を記載しアセット検証記録を追加
2026-09-16 chore: 右腎STLアセットとshapely依存を追加
    [kidney_right.stl]
2026-09-16 feat: 腎臓のボクセル化と走査断面との交差判定・履歴管理を実装
2026-09-16 feat: 腎臓走査のRerun表示・操作パネル・CLIオプションを追加
2026-09-16 test: 腎臓走査・操作パネル・フレームワーカー・画像出力のテストを追加
2026-09-16 docs: 腎臓走査機能の使い方と位置合わせ調査記録を追加
